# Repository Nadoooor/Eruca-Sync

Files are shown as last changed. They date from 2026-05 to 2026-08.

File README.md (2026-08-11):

# Eruca-Sync
-------
<p align="center">
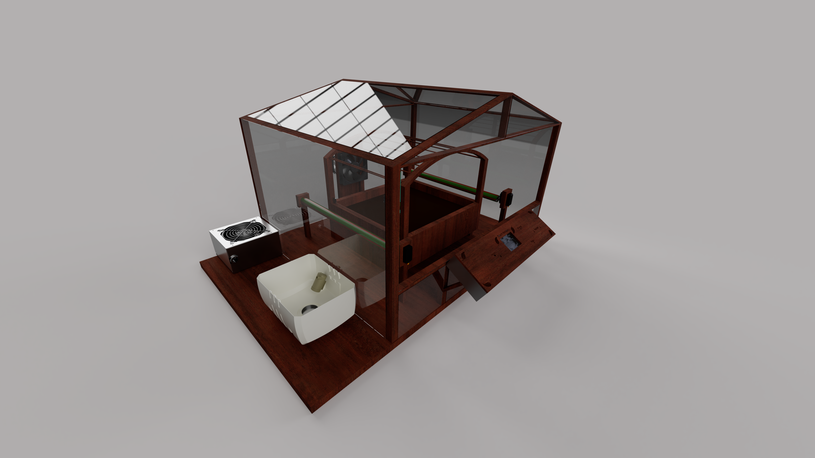
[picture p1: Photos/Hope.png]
Centered Image
  
</p>

--------
## Description:
A smart greenhouse with a closed-loop feedback system that can bring stability automatically to the system by itself. It focuses on green leafy plants and on three parameters. <br>

* Light intensity
* Soil moisture
* Temprature<br>

It has actuators that are responible of making the anti-changes that reverse any changes that occur in the environment, like temperature rise, soil drought, and over-light on the green leafy plants.<br>

### Why I am making this:
I made this because there are plants that I really want to try, but I can't plant them in my home because there is no suitable environment for them. So, the project will provide these plants with their suitable environment. For Example, around my home, I can't plant Eruca (Arugula) because of the direct sunlight and the high temperature. I really want to try planting Arugula, so I thought about how to plant it around my home, but with minimal effort. So, I got this idea to make a self-balancing environment for the Arugula or any plant species. 

### Highlight
The light mechanism is the most highlighted actuator here. It is composed of two servos and two pips, which rotate with each other to change different light transmissivity layers to increase the light intensity coming from the sun or decrease it.

## How it works:

1. First, just plug the power plug into any 220V power source. 
2. The screen will light up, asking which plant species you are planting. 
3. Choose the plant species, and that's it.
4. Leave it on its own; it will show you the real-time parameter readings as it is waiting for any changes to power up the actuators.

## Some photos of the project:

### PCB:<br>

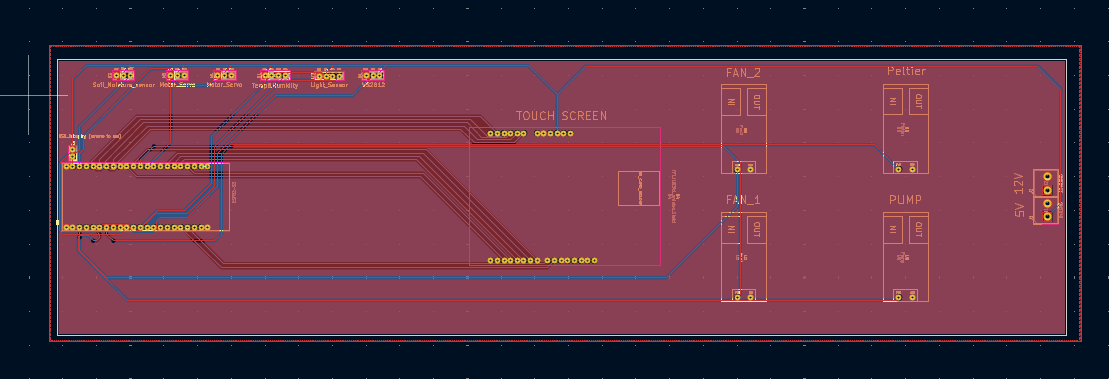
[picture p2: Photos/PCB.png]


### 3D PCB:<br>

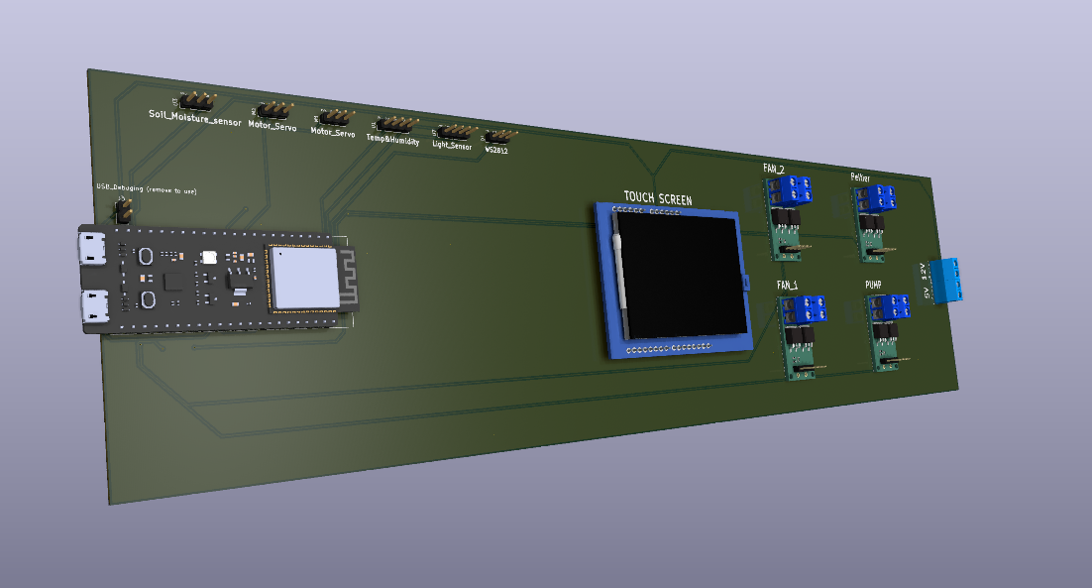
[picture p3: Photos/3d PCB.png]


### Schematic:

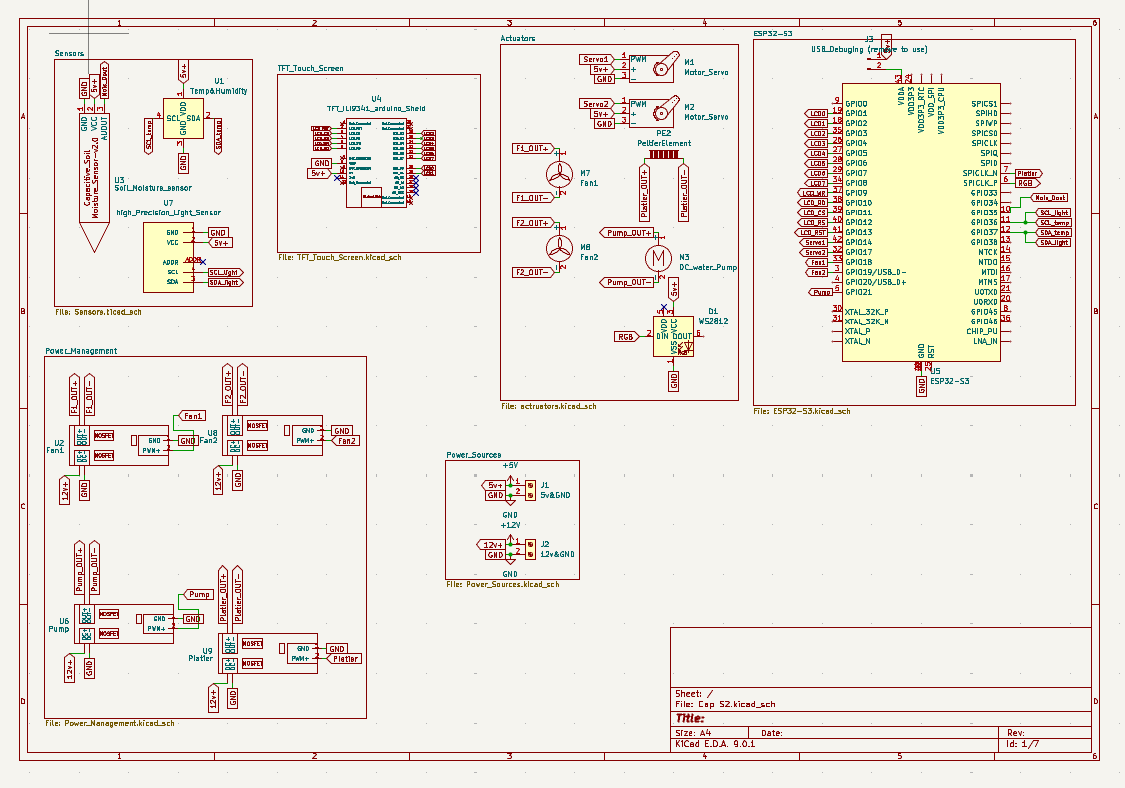
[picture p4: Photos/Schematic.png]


### 3D design:

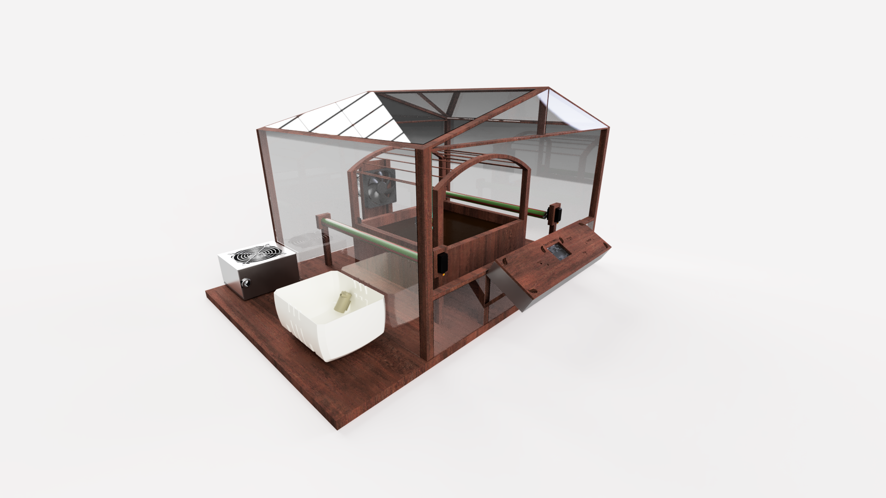
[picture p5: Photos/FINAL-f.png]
<br>
<br>
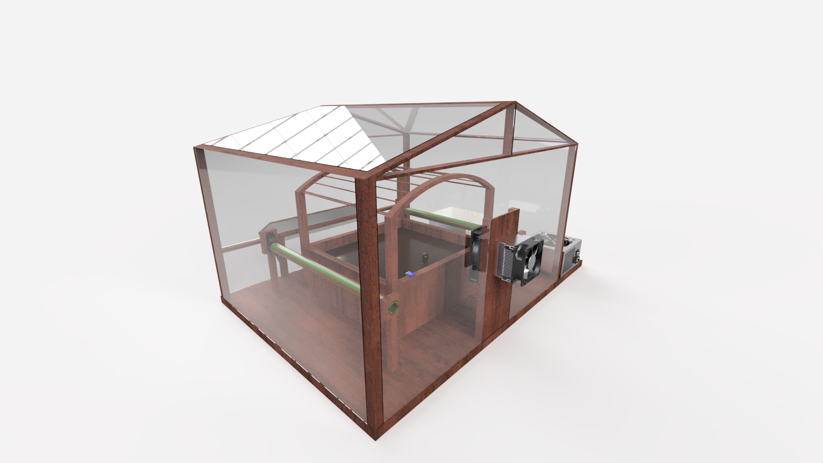
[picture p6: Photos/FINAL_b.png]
<br>

### IRL Photo:

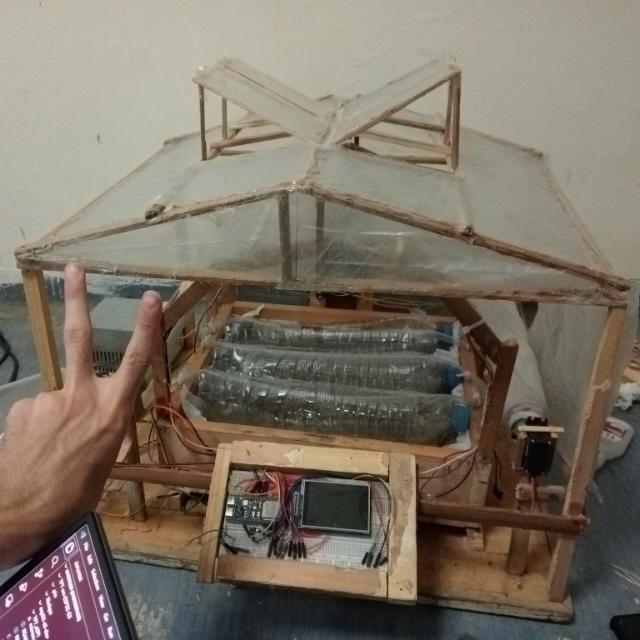
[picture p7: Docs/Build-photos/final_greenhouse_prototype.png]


> [!NOTE]
> Here you are the [Onshape Docs](https://cad.onshape.com/documents/9a096ebca3b52eda8b421bd5/w/291a79fda487721e4172dde6/e/f2d4edb63e0c7f47e937ec7d).
> Also the build journal [here](Docs/Build_Journal.md)

### Fallout Zine  :
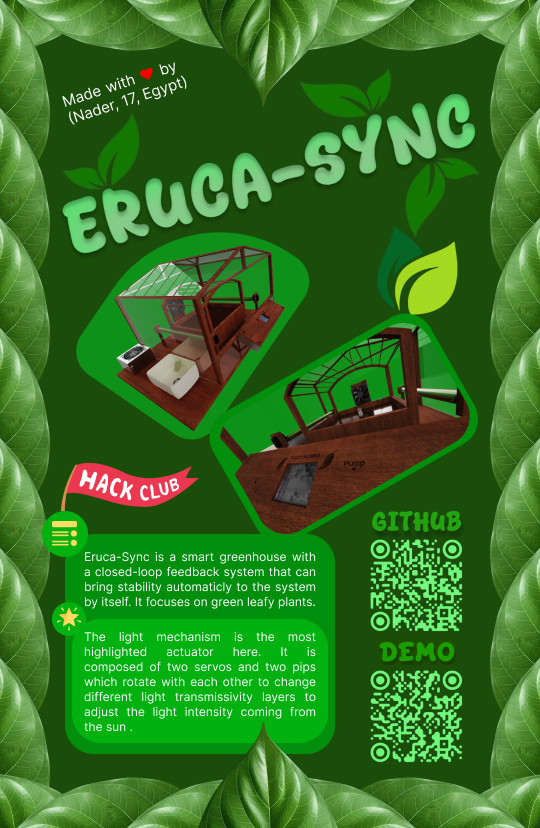
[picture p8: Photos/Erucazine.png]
<br>

## BOM (Bill of Materials)

---------------------------------------------
| Item Name | purchase links | Quantity | Price Per Unit | Total  |
|---|---|---|---|---|
| FS5106R Servo Motor 360° Continuous 6 kg.cm Plastic Gears | [Link](https://www.ram-e-shop.com/shop/servo-fs5106r-fs5106r-servo-motor-360deg-continuous-6-kg-cm-plastic-gears-7122) | 2 | $7.4 | $14.8  |
| AM-2320 Temperature & Humidity Calibrated Sensor | [Link](https://www.ram-e-shop.com/shop/sen-am2320-am-2320-temperature-humidity-calibrated-sensor-asair-r-original-brand-7776) | 1 | $3.28 | $3.28  |
| NeoPixel Stick 8-bit WS2812 5050 RGB LED | [Link](https://www.ram-e-shop.com/shop/kit-ws2812-8-5050-strip-neopixel-stick-8-bit-ws2812-5050-rgb-led-driver-development-board-8257) | 6 | $0.84 | $5.04  |
| Capacitive Analog Soil Moisture Sensor V2.0 | [Link](https://www.ram-e-shop.com/shop/sen-soil-c-capacitive-analog-soil-moisture-sensor-v2-0-sku-soil-c-8116) | 1 | $1.87 | $1.87  |
| BH1750 Light Calibrated Sensor | [Link](https://ar.aliexpress.com/item/1005009671465215.html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) | 5 | $1.31 | $6.55  |
| Water Pump 3-6Vdc Mini 120L/H | [Link](https://www.ram-e-shop.com/shop/dc-pump-6vdc-water-pump-3-6vdc-mini-120l-h-7422) | 1 | $0.84 | $0.84  |
| Thermoelectric Cooler 40x40mm - Peltier | [Link](https://www.ram-e-shop.com/shop/sf10080-thermoelectric-cooler-40x40mm-peltier-6726) | 1 | $2.81 | $2.81  |
| Aluminum Heatsink HS.13 Size 40x40x11 mm | [Link](https://www.ram-e-shop.com/shop/hs13-aluminum-heatsink-hs-13-size-40x40x11-mm-7713) | 1 | $0.52 | $0.52  |
| Kit MOSFET 15A 400W - Trigger Switch Drive Module | [Link](https://www.ram-e-shop.com/shop/kit-mosfet-15a-400w-kit-mosfet-15a-400w-trigger-switch-drive-module-with-pwm-regulator-control-8008) | 5 | $0.84 | $4.22  |
| PC Old Power Supply - 200W | [Link](https://www.dubizzle.com.eg/en/electronics-home-appliances/computers-accessories/q-power-supply/) | 1 | $2 | $2 |
| Old PC CPU Cooler with its Fan | [Link](https://www.dubizzle.com.eg/en/ad/amd-cpu-stock-fan-ID207435960.html) | 1 | $5.62 | $5.62  |
| Old PC Fan 12cm | [Link](https://www.dubizzle.com.eg/en/ad/%D9%85%D8%B1%D9%88%D8%AD%D8%A9-%D8%A7%D9%84%D9%83%D9%85%D8%A8%D9%8A%D9%88%D8%AA%D8%B1-pc-case-fan-ID207415788.html) | 1 | $1.56 | $1.56  |
| Water Container (Any bottle or box) | [Link](https://www.amazon.eg/-/en/elyassin-plastic-food-container-size/dp/B0C4K14QZV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) | 1 | $1.3 | $1.3 |
| Wood with the dimensions (all the dimensions are in the onshape) | Bro any Cabinetmaker you don't need a link for that but [At least this will help](https://goodwood.com.eg/en/new-details.php?id=5973) *(For me i used recycled wood from my school)* | ~~~ | Vary | Vary |
| LCD TFT 2.8 inch Touch Display with ILI9341 Driver 8bit Parallel | [Link](https://www.ram-e-shop.com/shop/kit-lcd-tft-2-8-touch-lcd-tft-2-8-inch-touch-display-for-arduino-uno-mega2560-8003) | 1 | $12.18 | $12.18 |
| ESP32-S3-N16R8 Development Board WIFI and Bluetooth | [Link](https://mostelectronic.com/shop/arduino-development-boards/esp32-s3-n16r8-development-board-wifi-and-bluetooth/) | 1 | $14.06 | $14.06 |
| PVC pipes as the rotation axies | As well as the wood (plz don't buy it online it is so cheap out there) | 2 x 0.5 meter | $3 | $6 |
| Plastic baggs or plastic sheets | Recycled as well | ~~~ | ~~~ | ~~~ |
| Jumper Wires | [Link](https://www.ram-e-shop.com/shop/ph61-mm-20cm-ph61-20cm-male-to-male-40-jumper-wires-set-7094) | 60 | $0.019 | $1.14  |
| Some Nails | The same place as the pipes | 30 | $0.027 | $0.8 |
| MDF Fast Adhesive Glue | [Link](https://www.amazon.eg/-/en/Akfix-705-Universal-Fast-Adhesive/dp/B07MCQWCQV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) | 2 | $3.18 | $6.36  |
| PCB | [Link](https://uge-one.com/pcb-print-design/?srsltid=AfmBOopBK8awYYikG2a9qXKbW5DigASPA7Sdrr7dOJ97qQsz4a_aT9M1) | 1 | $20 | $20|
| Shipping | ~~~~~~~~~~ | ~~~ | ~~~ | $6.74  |
| Total | ~~~~~~~~~~ | ~~~ | ~~~ | $117.69 |

## How to build the Code:
1. Install PIO (PlatformIO) and clone the repo
2. Open the Eruca-Sync-Code folder, which has the source code in PlatformIO VS Code.
3. Do whatever you want, edit, add, remove, etc.
4. Just click the check mark down there in VS Code to build the code into a .bin and .elf files.
5. Or just click the arrow icon while connecting the ESP to the PC/Laptop to directly compile and upload the code.
6. Enjoy ;)

## How to build the structure:
1. Get wood with the right dimensions(You will find them in the Onshape docs).
2. For the arc on top of the planting area, you can laser cut them along the motor and pipe holders
3. Use the Nails to install all four columns (You can, like, put the nail in its place on the base, and then take it back and cut its head and put it again, and then install the column using a hammer as I did with mine)
4. When you finish the structure using nails and wood, you can then take the fan part, and first you should cut a thin wood rectangle piece(like in the 3D), and then nail the two short columns on top of its sides.
5. Screw the PC fan and the PC cooling part 
6. After that, install the full piece with the same method as the regular columns.
7. Install the wooden planting area, which has the arc and columns on top. (with the same techniques).
8. Put the light sensor and the temperature in the middle of any side of the planting area. (you can use two lil screw or MDF glue).
9. Put the soil in the planting area (And place the soil moisture sensor in the middle of it).
10. You can connect the four outer columns with tall wooden horizontal pieces to make it stable if it is not.
11. Make two identical Rectangles for the roof with the dimensions.
12. Place them at a 30-degree angle from the horizontal so they can make a triangle with each other.
13. Install the Control Panel box on the front side of the structure at an angle of 45 degrees with two small wooden pieces under it to make it stable. (Glue the box to those pieces with MDF and use a nail on the other side in the two little columns.
14. Add the PCB and wire everything to its place on the PCB.
15. Place the power supply and the water container.
16. Use plastic bags or acrylic sheets to cover the greenhouse.
17. Upload the code 
18. That's it, enjoy. ❤️
-----------------

# Made with ❤️ By Nadooor

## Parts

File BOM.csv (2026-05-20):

Item Name | purchase links | Quantity | Price Per Unit | Total
FS5106R Servo Motor 360° Continuous 6 kg.cm Plastic Gears | https://www.ram-e-shop.com/shop/servo-fs5106r-fs5106r-servo-motor-360deg-continuous-6-kg-cm-plastic-gears-7122 | 2 | $7.4 | $14.8
AM-2320 Temperature & Humidity Calibrated Sensor | https://www.ram-e-shop.com/shop/sen-am2320-am-2320-temperature-humidity-calibrated-sensor-asair-r-original-brand-7776 | 1 | $3.28 | $3.28
NeoPixel Stick 8-bit WS2812 5050 RGB LED | https://www.ram-e-shop.com/shop/kit-ws2812-8-5050-strip-neopixel-stick-8-bit-ws2812-5050-rgb-led-driver-development-board-8257 | 6 | $0.84 | $5.04
Capacitive Analog Soil Moisture Sensor V2.0 | https://www.ram-e-shop.com/shop/sen-soil-c-capacitive-analog-soil-moisture-sensor-v2-0-sku-soil-c-8116 | 1 | $1.87 | $1.87
BH1750 Light Calibrated Sensor | https://ar.aliexpress.com/item/1005009671465215.html?curPageLogUid=4LlmP7toFGiX | 5 | $1.31 | $6.55
Water Pump 3-6Vdc Mini 120L/H | https://www.ram-e-shop.com/shop/dc-pump-6vdc-water-pump-3-6vdc-mini-120l-h-7422 | 1 | $0.84 | $0.84
Thermoelectric Cooler 40x40mm - Peltier | https://www.ram-e-shop.com/shop/sf10080-thermoelectric-cooler-40x40mm-peltier-6726 | 1 | $2.81 | $2.81
Aluminum Heatsink HS.13 Size 40x40x11 mm | https://www.ram-e-shop.com/shop/hs13-aluminum-heatsink-hs-13-size-40x40x11-mm-7713 | 1 | $0.52 | $0.52
Kit MOSFET 15A 400W - Trigger Switch Drive Module | https://www.ram-e-shop.com/shop/kit-mosfet-15a-400w-kit-mosfet-15a-400w-trigger-switch-drive-module-with-pwm-regulator-control-8008 | 5 | $0.84 | $4.22
PC Old Power Supply - 200W | https://www.dubizzle.com.eg/en/electronics-home-appliances/computers-accessories/q-power-supply/ | 1 | $2 | $2
Old PC CPU Cooler with its Fan | https://www.dubizzle.com.eg/en/ad/amd-cpu-stock-fan-ID207435960.html | 1 | $5.62 | $5.62
Old PC Fan 12cm | https://www.dubizzle.com.eg/en/ad/%D9%85%D8%B1%D9%88%D8%A2%D8%A9-%D8%A7%D9%84%D9%83%D9%85%D8%A8%D9%8A%D9%88%D8%AA%D8%B1-pc-case-fan-ID207415788.html | 1 | $1.56 | $1.56
Water Container (Any bottle or box) | https://www.amazon.eg/-/en/elyassin-plastic-food-container-size/dp/B0C4K14QZV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 | 1 | $1.3 | $1.3
Wood with the dimensions (I used recycled wood)(all the dimensions are in the onshape) | https://goodwood.com.eg/en/new-details.php?id=5973 | ~~~ | Vary | Vary
Plastic bags or plastic sheets | https://www.amazon.eg/-/en/Zpac-freezer-bag-heavy-duty/dp/B09T3HLTGR | ~~~ | ~~~ | ~~~
Jumper Wires | https://www.ram-e-shop.com/shop/ph61-mm-20cm-ph61-20cm-male-to-male-40-jumper-wires-set-7094 | 60 | $0.019 | $1.14
LCD TFT 2.8 inch Touch Display with ILI9341 Driver 8bit Parallel | https://www.ram-e-shop.com/shop/kit-lcd-tft-2-8-touch-lcd-tft-2-8-inch-touch-display-for-arduino-uno-mega2560-8003 | 1 | $12.18 | $12.18
ESP32-S3-N16R8 Development Board WIFI and Bluetooth | https://mostelectronic.com/shop/arduino-development-boards/esp32-s3-n16r8-development-board-wifi-and-bluetooth/ | 1 | $14.06 | $14.06
PVC pipes as the rotation axies | https://hegazy-group.com/products/engineering-home-pvc-elecetrical-pipe-25mm-3-meter | 2 x 0.5 meter | $3 | $6
Some Nails | https://www.amazon.eg/-/en/1-2mm-Plain-Steel-Joinery-Nails/dp/B09CDNXTX5?mcid=a3513e1143233c7d97289a4cd67e9979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 | 30 | $0.027 | $0.8
MDF Fast Adhesive Glue | https://www.amazon.eg/-/en/Akfix-705-Universal-Fast-Adhesive/dp/B07MCQWCQV | 2 | $3.18 | $6.36
PCB | https://uge-one.com/pcb-print-design/ | 1 | $20 | $20
Shipping | ~~~~~~~~~~ | ~~~ | ~~~ | $6.74
Total | ~~~~~~~~~~ | ~~~ | ~~~ | $117.69

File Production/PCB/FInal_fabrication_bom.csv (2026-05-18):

Designator | Footprint | Quantity | Value | LCSC Part #
D1 | PinHeader_1x03_P2.54mm_Vertical | 1 | WS2812
J1 | Altech_AK100_1x02_P5.00mm | 1 | 5v&GND
J2 | Altech_AK100_1x02_P5.00mm | 1 | 12v&GND
J3 | PinHeader_1x02_P2.54mm_Vertical | 1 | USB_Debuging (remove to use)
M1, M2 | PinHeader_1x03_P2.54mm_Vertical | 2 | Motor_Servo
U1 | PinHeader_1x04_P2.54mm_Vertical | 1 | Temp&Humidity
U2 | MOSFET_KIT | 1 | Fan1
U3 | PinHeader_1x03_P2.54mm_Vertical | 1 | Soil_Moisture_sensor
U4 | TFT_SCREEN | 1 | TFT_ILI9341_arduino_Sheid
U5 | ESP32-S3-DEVKITC-1 | 1 | ESP32-S3
U6 | MOSFET_KIT | 1 | Pump
U7 | PinHeader_1x04_P2.54mm_Vertical | 1 | Light_Sensor
U8 | MOSFET_KIT | 1 | Fan2
U9 | MOSFET_KIT | 1 | Platier

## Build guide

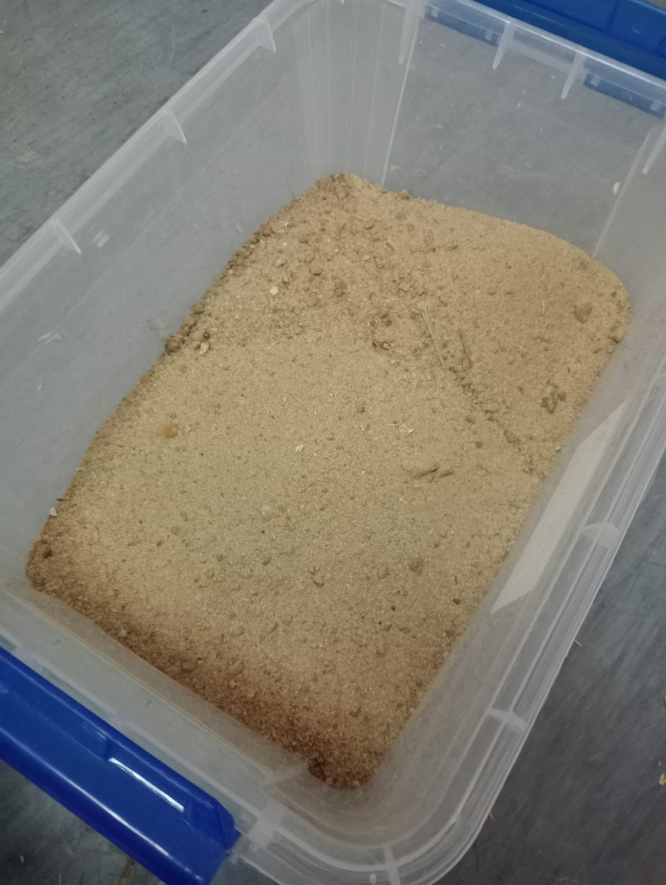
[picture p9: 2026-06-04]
Docs/Build-photos/regular sand.jpg

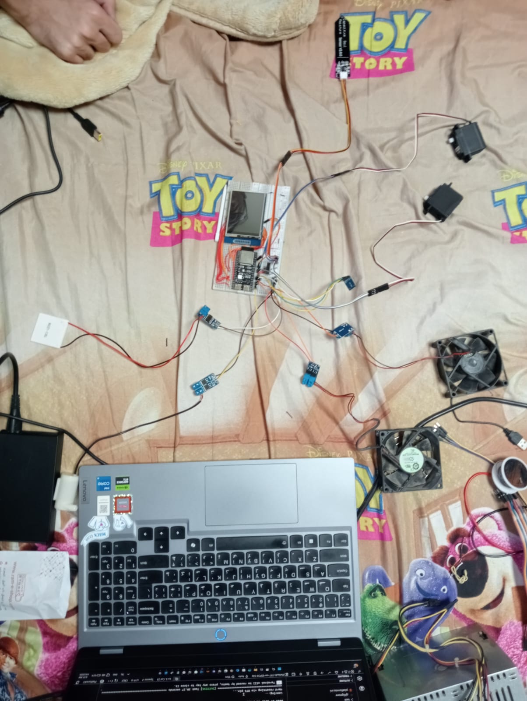
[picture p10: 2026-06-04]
Docs/Build-photos/connecting circuit for the first time.jpg

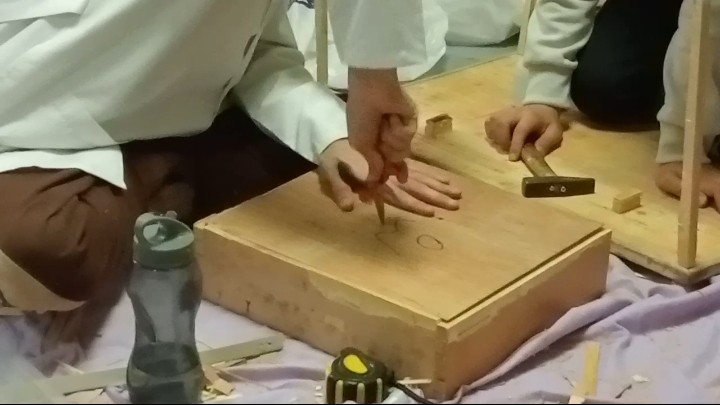
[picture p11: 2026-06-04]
Docs/Build-photos/piercing the bottom of the planting box.jpg

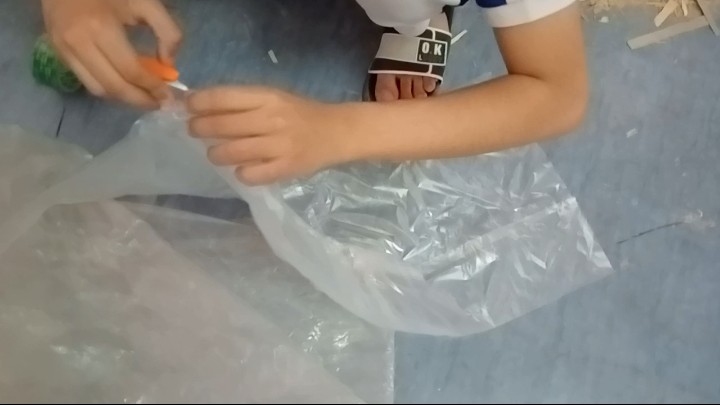
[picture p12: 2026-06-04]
Docs/Build-photos/cutting plastic sheet.jpg

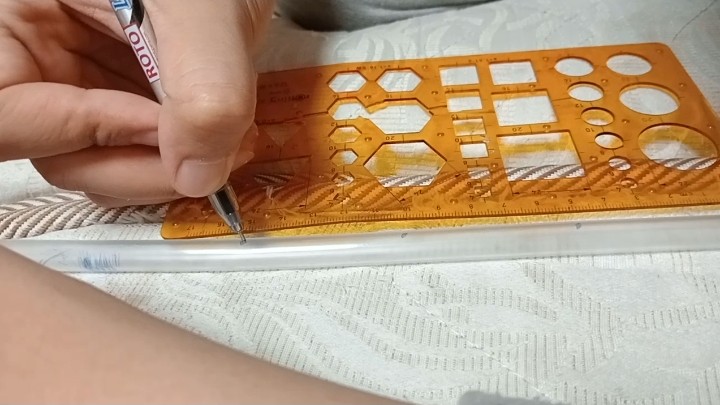
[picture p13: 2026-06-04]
Docs/Build-photos/marking the holes on the plastic tube.jpg

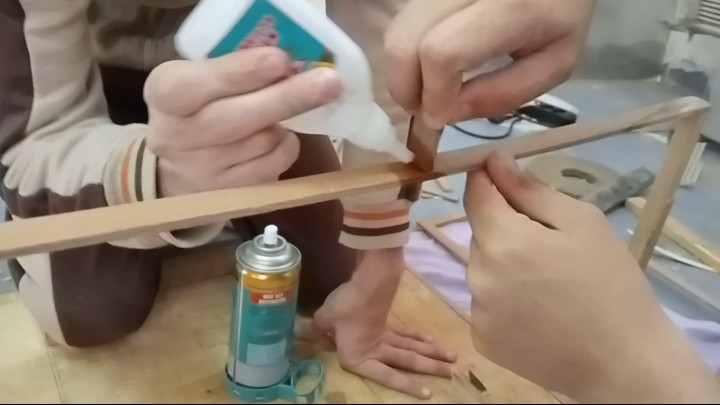
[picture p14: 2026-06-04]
Docs/Build-photos/connecting wooden pieces with MDF.jpg

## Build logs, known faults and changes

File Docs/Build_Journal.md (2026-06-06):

# Build Journal

--------------------------

### Total Build Hours: 56 Hours

<br>

## Day 1

- **Date:** 1/4/2026
- **Total hours spent:** 5 Hours

My school wants me to finish this project in just a week :C, it will be a so exhausting week, but that's fine I can do it.

Well, I was looking for a recycled wood. I kept searching until I found this super cool place on my school's backyard. 

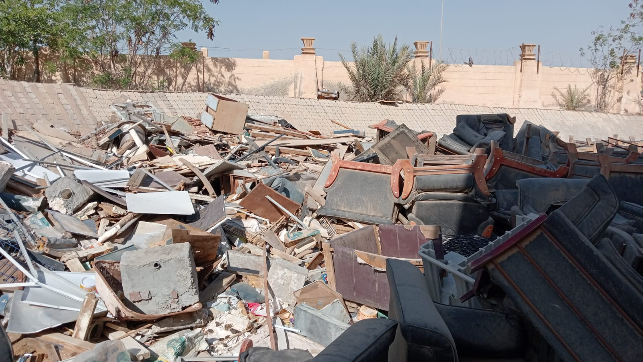
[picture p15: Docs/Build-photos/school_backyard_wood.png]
School Backyard Recycled Wood Spot


So, I took this old desk and took the top layer from it so I can use it as the base.

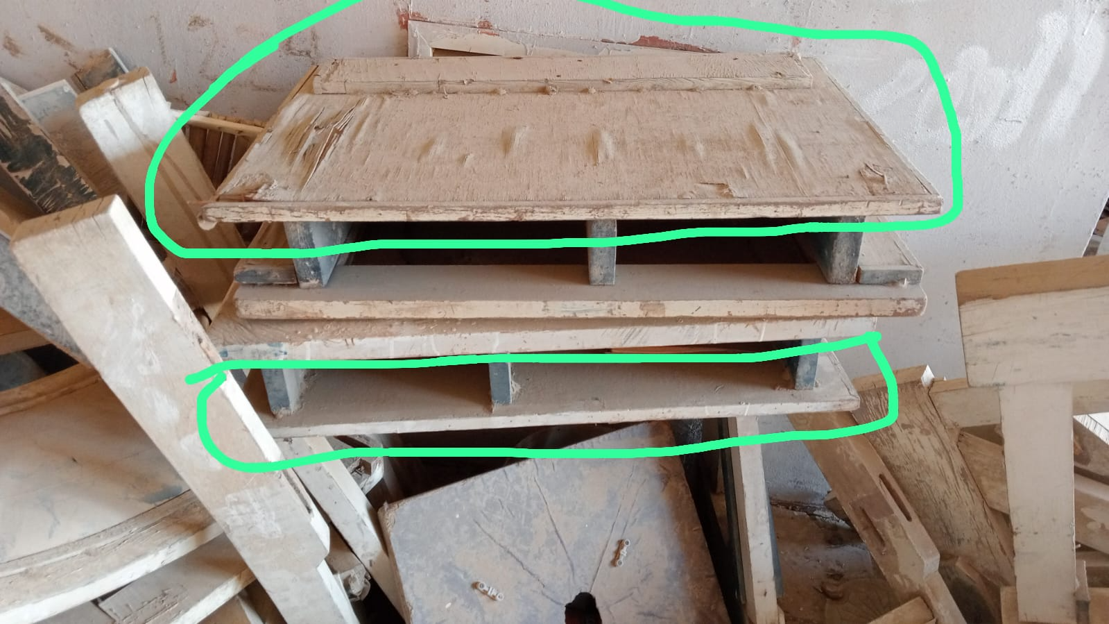
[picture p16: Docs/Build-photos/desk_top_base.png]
Old Desk Top Layer Base


I also found some materials in my home like the PVC pipe and thin wood that I can make the sealing and the supporters with it. 

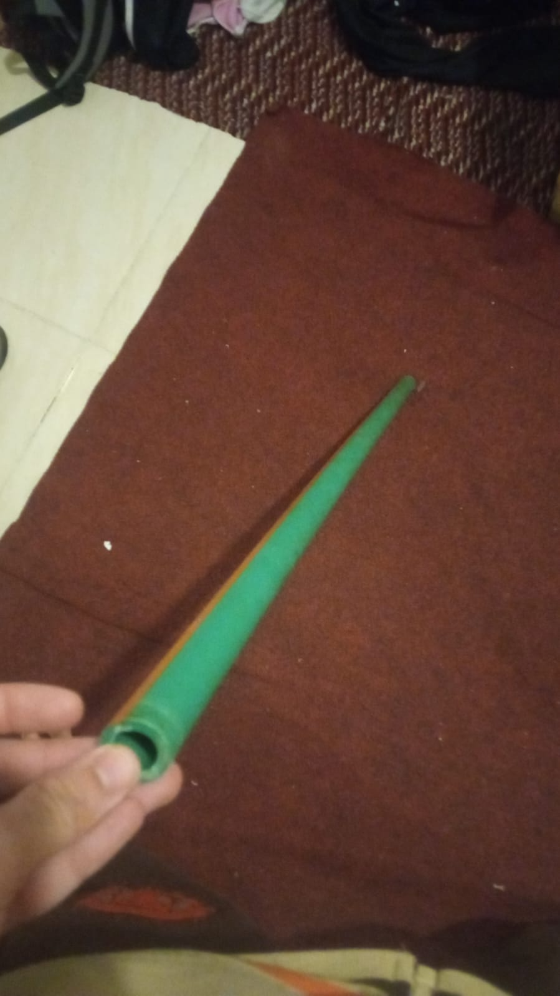
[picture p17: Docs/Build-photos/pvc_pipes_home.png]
PVC Pipes Found At Home

Thin Wood Supporters

*(The searching process didn't count on the total Hours.)*

Well, after that I started by building the outer structure. Well, I was searching for the Wood columns that I will use. But the supporter wood I found in my home can't be used as columns as it is kinda thin. 

So, I found old drawers that can be used as columns after breaking them down. 

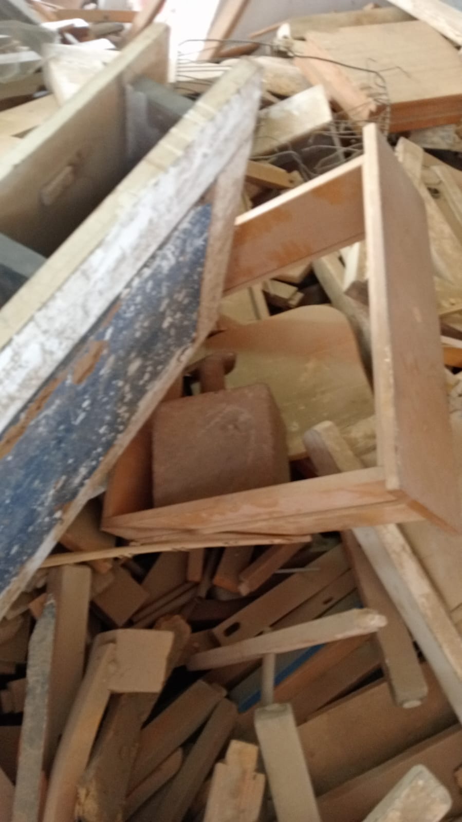
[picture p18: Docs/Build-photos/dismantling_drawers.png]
Dismantling Old Drawers For Parts

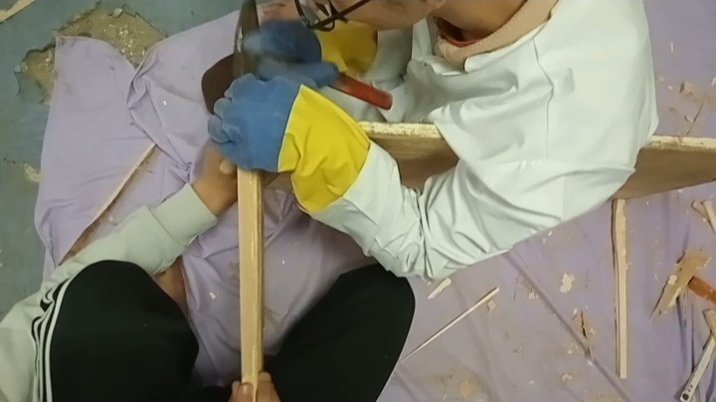
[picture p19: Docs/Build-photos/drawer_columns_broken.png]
Drawer Wood Cut Into Columns


Then I put nails from the bottom of the base to each column so they can stick to the base and also used MDF glue to make it more solid. 

After that, of course the four wooden columns won't be that super solid so I used the supporter wood pieces I made so I can connect the four columns with each other and after that they were so much solid. 

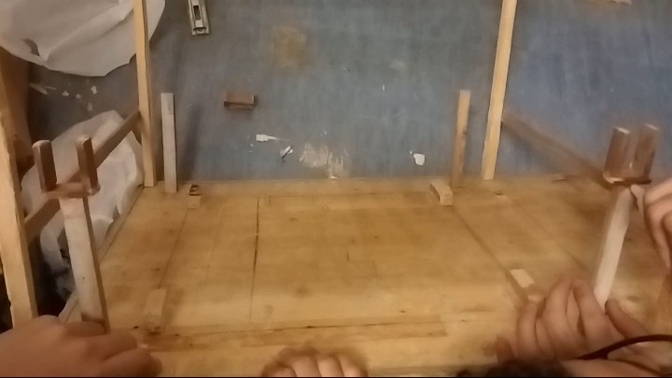
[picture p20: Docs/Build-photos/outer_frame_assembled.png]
Reinforced Outer Structure Frame


<br>

## Day 2

- **Date:** 2/4/2026
- **Total hours spent:** 7 Hours

I was very exhausted yesterday because I went to school without the bus with all the materials and ALSOOo worked on the project as I said above :c.

But now I slept well and can work a lil longer. So, let's go.

First, I started by setting up the soil for the plants and used an old full drawer for that. To prepare the planting base, I mixed the soil with peat moss and sand.

* **Video Link:** [Making the Peat Moss Soil](https://youtu.be/yI6NNnzTHSI)

And we placed an internal plastic bag so it can protect the drawer's wood from getting rotten. Once the protective layer was secure, I poured the freshly prepared mixture in.

* **Video Link:** [Pouring the Peat Moss Soil](https://youtube.com/shorts/tnRFBcnSGDY?feature=share)
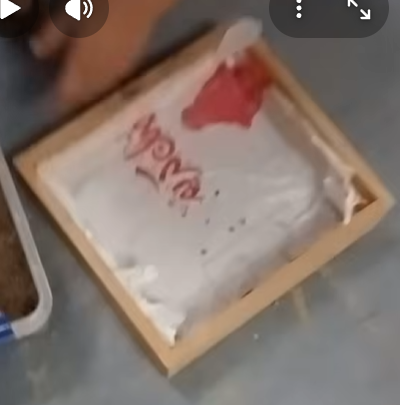
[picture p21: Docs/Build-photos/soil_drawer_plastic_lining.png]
Soil Drawer with Plastic Lining
* **Image Reference:** 

And yeah before putting the drawer into the structure, I also made another four columns for the motors and the light mechanism with its motor and PVC pipe holders. And with the same technique I used nails to reinforce them. 

After putting the soil inside the drawer, I placed the drawer inside the outer structure with some small wood pieces that will lift it a lil from the base so we can collect the water in a small plate.

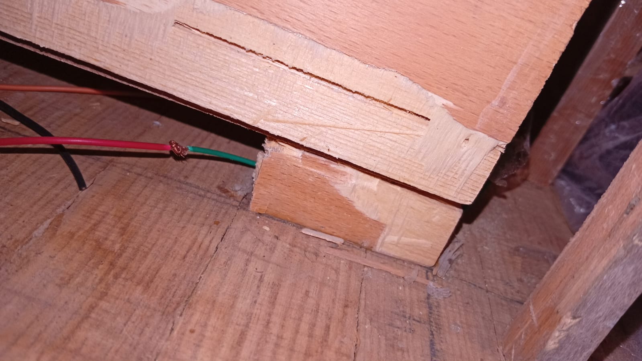
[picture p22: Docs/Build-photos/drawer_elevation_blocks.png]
Lifting Blocks Under Soil Drawer


After putting the soil drawer inside the structure, I started building the cooling system wooden structure and fans places. Well, this one needed to be built separately first and then install it into the main structure after it is considered ready. 

So, I just took a wooden thin plate and then cut it with the dimensions in the 3D, after that I got two small columns and put them on top of the wooden plate. And used nails to stick them together. 

After that I put the fans on top each side and marked the nails places, and marked also the square where the cooling Peltier will be placed. Then I cut it and placed the Peltier and added on the hot side some thermal paste and then added the PC cooling fan that came with the heat sink. On the cold side I added the heat sink with the thermal paste and then added the PC normal fan and used the screws to reinforce everything.  

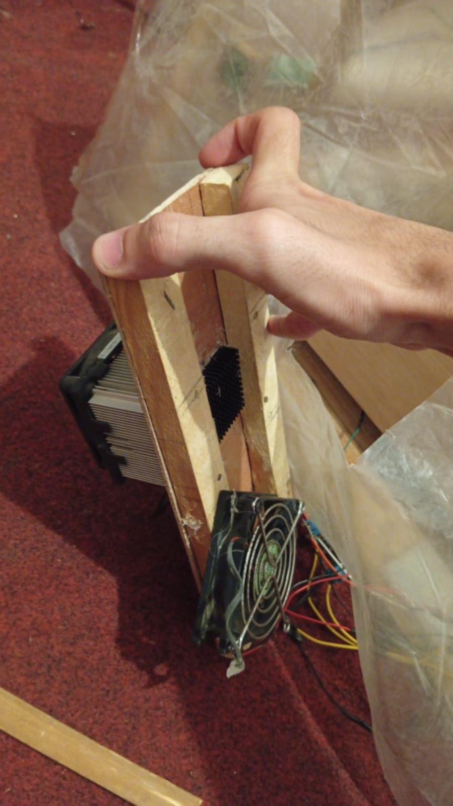
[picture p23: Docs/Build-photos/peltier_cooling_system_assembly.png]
Peltier Cooling Module Setup and Fans


After that, it's time to install this part onto the main structure. Well, as usual I used the regular technique and used nails and MDF glue to reinforce it into the main structure and yeah connected it to the supporter wood. 

After finishing that part, I worked on the sealing structure and focused on making it as like as the shape we need and I made in the 3D. 

So, I started with making two rectangles with the dimensions. But I remembered that I need to reinforce that all when I finish many other things like the arcs of the light mechanism and so on. 

So, I stopped working for today and will continue in the next session. 

<br>

## Day 3

- **Date:** 3/4/2026
- **Total hours spent:** 6.5 Hours

I can see progress yay!

After that hard time in the last session, I killed myself on the bed for exactly 4 hours and then let's WORK again. I must finish this on time. 

Well, when I remembered that I need to delay the reinforcing of the sealing, I remembered that because I thought how I will install the arc and the light mechanism.

So, here we are building this. Well, this one was so funny. At first we were trying to just cut the supporter wood as regular small rectangles and place them on top of each other with the specified angles to make it as an arc. 

We decided to make it look prettier. We cut the wooden small rectangles while they are on top of each other so we can cut them with the same angles and shape the arc as a smooth arch, not wooden pieces placed on top of each other.  

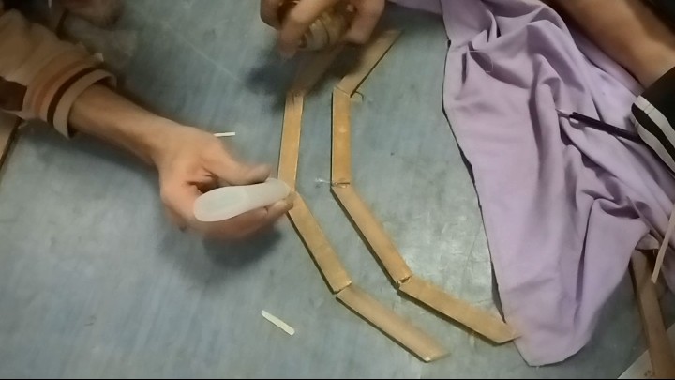
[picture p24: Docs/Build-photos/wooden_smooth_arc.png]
Shaped Wooden Smooth Arch


Well, now we need to talk about the arcs' columns which will have the arcs and the transparent bags mechanism above it. 

Ahh, this one was kinda weird. First I got the wooden columns as usual from destroying the old drawers. But when we look at the technique I was using to reinforce the columns with the nails... well, I can't do this here. This technique needs me to grab the column with my hand and put it in the required place and then using the nails and a hammer, I can drive the nail into the base from the other side through the base and to the column. But here, well the other side is too far. I can't use regular sized nails and also the tall nails can break the wood. 

So, I got a very cool idea. Well first I grabbed the columns, and using the hammer I drove the nail into the down side of the column separately without the soil drawer. I drove the nail a lil bit which can make a hole that the nail can be placed into. 

After that, I extracted the nail, and then cut its head, and then I re-drove the head side of the nail into the hole I made. After that, I grabbed the column to its place on the drawer, and finally I drove the whole column using the hammer as it works as the nail's head. 

Repeated that with the remaining 3 columns and yeah... I got these columns solid and well placed with that cool idea. I loved it so much tbh it was so funny.

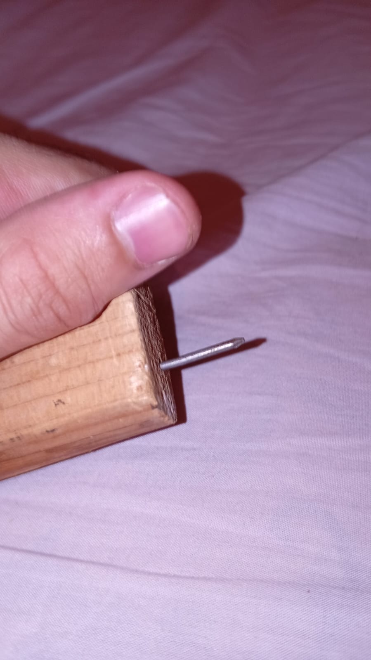
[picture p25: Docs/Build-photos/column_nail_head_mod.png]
Nail Mod Installation Hack for Columns


After this great step, I got the servo motors and connected the PVC pipes using MDF glue and very small nails into the +-shaped-gear of the servo. But at first I used the servo screw to connect the gear into the servo itself, because the screw can only be driven from the inside of the PVC pipe and it is very tall for any of my screwdrivers. 

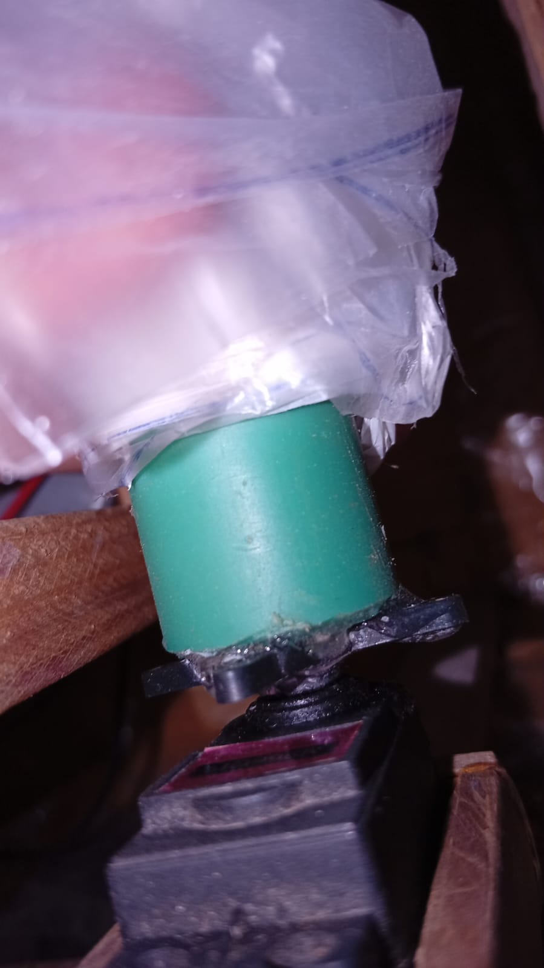
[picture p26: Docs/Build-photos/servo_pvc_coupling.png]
Servo Coupling Inside PVC Pipe


After that, I decided to make the very tall sheet of different transparent layers that will control the light intensity of the sun. Well, we took the measurement of the pipe's length and with a marker I drew the same length many times in parallel along each layer of bags so I can cut them and finally connect them with each other to make a chain of bags. Each end should be connected to the PVC pipe on each servo. 

* **Video Link:** [Testing the Light Transparent Bags Mechanism](https://www.youtube.com/shorts/U7GsUwmneE8?feature=share)

But I was very tired. So, let's call it a day and sleep the same 4-6 hours and continue work tomorrow.

<br>

## Day 4

- **Date:** 4/4/2026
- **Total hours spent:** 8 Hours

YAY, a lot of things are finished and yeah I need this time to focus on making the circuit and testing it up. 

My head hurts a lil and I didn't sleep well but I must finish this :|

Ok, started by testing up the circuit. Well, the most hard part was the screen. It was so exhausting as it has many pins and any small fault will make me search a lot about where it is. So, I made it very carefully and used small wires so it doesn't appear so overwhelming compared to the regular jumpers. 

Also, yeah I used a regular breadboard because the PCB will take time and I don't have it. It is 4 days till my exhibition and it must be fully functionable and tested. So, I used two breadboards and removed one power line from one of them and connected both of them with each other so they can perfectly size the weird ESP32-S3 width and the TFT touch screen width. 

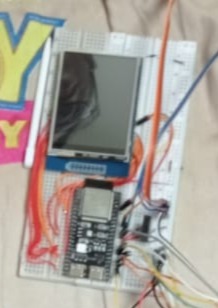
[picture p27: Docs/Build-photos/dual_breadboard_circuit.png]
Dual Breadboard Circuit Layout


After that I wired all the pins with the ESP32-S3 and found that the display doesn't want to turn on. So, I searched a lot why even the backlight doesn't want to turn on even if the backlight uses 3V3 and doesn't need 5V0. Didn't find good info on the internet tbh so I just grabbed the display myself and traced it with my eyes. And yeah I found the very stupid problem. 

Yeah the display is using a voltage regulator. And this voltage regulator must take the 5V0 and convert it into 3V3, and it can't just take 3V3 and give 3V3. So, I kept searching if I can find any jumper pads on the TFT board but I didn't find. It seems that my TFT model doesn't come with these pads. So, for now I just used an external 5V0 from the Arduino and also connected all the GNDs and just tried the TFT with the ESP32-S3 to make sure it works... and it worked! 

When I connect everything in the control panel in the prototype I can just take 5V0 from the Power Supply Unit and give it to the TFT screen and just take 3V3 from the same unit to the other components. I am using a PC power supply, so this helps so much in getting different voltages without the need of step-ups or step-downs. 

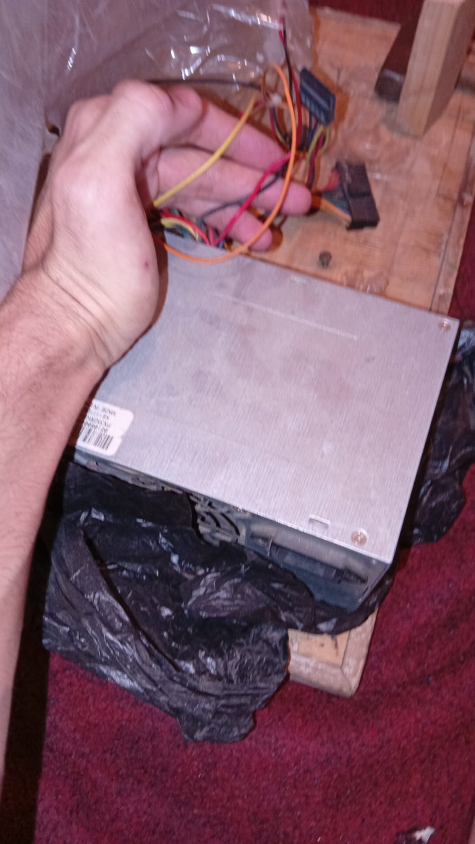
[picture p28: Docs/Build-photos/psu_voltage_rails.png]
PC Power Supply Unit Interfacing


After that I used all the remaining pins to connect the actuators and the sensors. The sensors regularly took 3.3V from the ESP32 directly. But for the actuators they were using MOSFETs so the fans and the Peltier took 12V from the PSU and the MOSFET itself gave a PWM which is connected to the ESP32 PWM pins to control the actuators. And for the water pump it is all the same except I connected it with 5V not 12V.

Tested the circuit and all the components, it was kinda weird. But after some debugging it worked. 

After that I started working on the control panel structure. Well, this one's dimensions specifically needed to be changed. Because I am using a breadboard this time which is smaller than the PCB I made. So I took the measurements of the breadboard and made a frame around it using the same drawer I destroyed and also used the same technique I used when I made the cooling system. And made two holes for the wires from the bottom side. And made another thin wooden sheet to be like the cover of the control panel, and I made a rectangle hole for the screen.

After making that wooden control panel, I made two more lil columns and placed them on the front side aligned to the other main columns. And these columns were at the same height as the supporter wood. After driving these two columns and also making two angled supporters (to make the control panel angled to the user), I placed the control panel on them (they were in the middle) and then using nails I placed its top frame stick on the columns and then I pushed the control panel a lil downwards till it touches the two angled supporters. And then using MDF to just make it stick to the two supporters and then using two very thin nails I made it very solid and well angled.

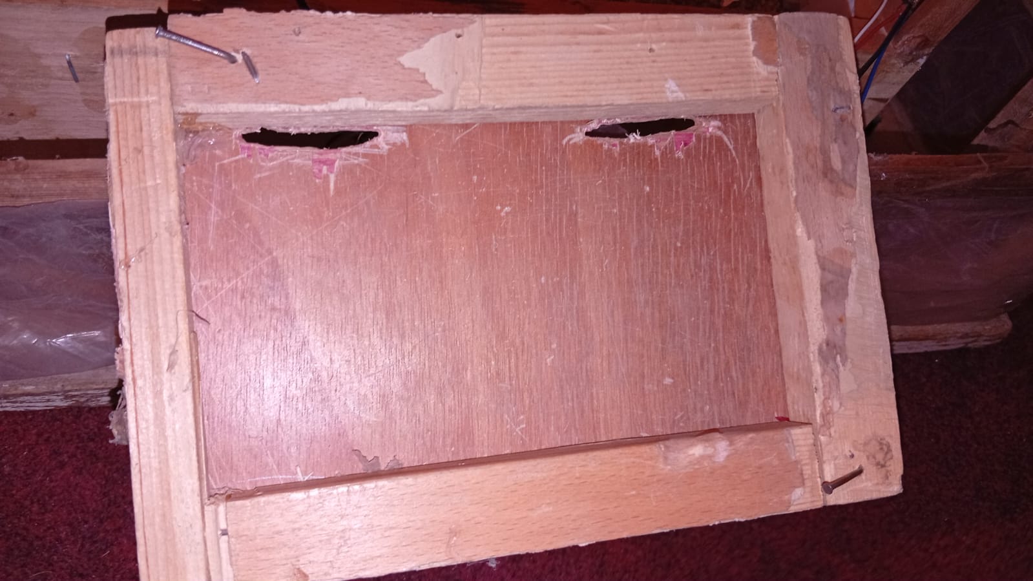
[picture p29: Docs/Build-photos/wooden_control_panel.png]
Angled Wooden Control Panel Frame


<br>

## Day 5

- **Date:** 5/4/2026
- **Hours:** 7 Hours

The project is likely at 80% progress.

Well, this time tbh I slept well so I am ready to insert all the circuit into the project.

Well, after installing the control panel on the structure, I started installing all the sensors and the actuators.

Well, I placed the breadboard that has the ESP32 and the TFT screen wired on it into the control panel structure. It fit perfectly and it was so cool and well angled. Well, the wood is not that perfect but at least I am the one who made it from scratch. 

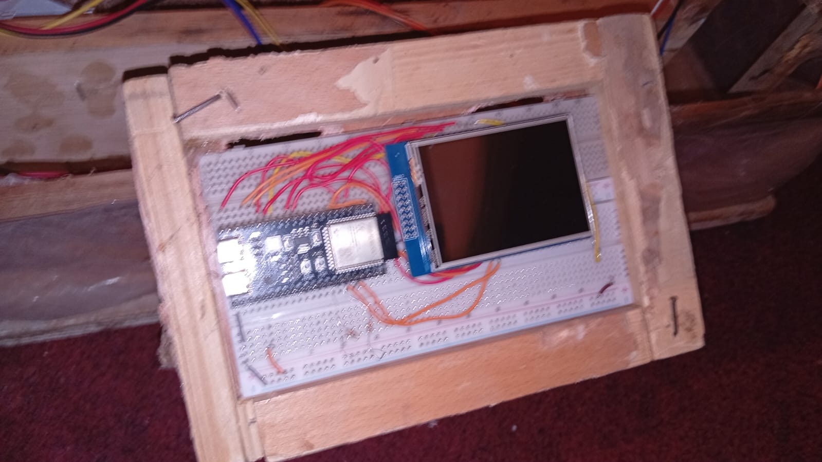
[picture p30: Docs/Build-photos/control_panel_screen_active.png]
TFT Display Running Inside Panel


After that, I placed all the sensors in their places. Placing the sensors on their places was not the problem. The wiring was the problem. It was so overwhelming because the wires had to be so long to reach the control panel. And accidentally I got short wires so I needed to connect them with each other to make one big wire and connect each sensor with 4 or 3 of these long wires. So it was kinda hard to make that all but yeah I made it. 

Well, for the actuators it was kinda different where I just needed a maximum of 2 wires for the control, and for the power also 2, but these are directly coming from the PSU. 

So I wired the fans and the Peltier and the water pump easier than the sensors. And yeah of course all of the wires are routed from the bottom of the control panel (the two holes I made). To verify the fluid integration, I mounted the automated watering system for a quick diagnostic check.

* **Video Link:** [Installing the Irrigation System for Testing](https://youtu.be/krxk9sDdObg)
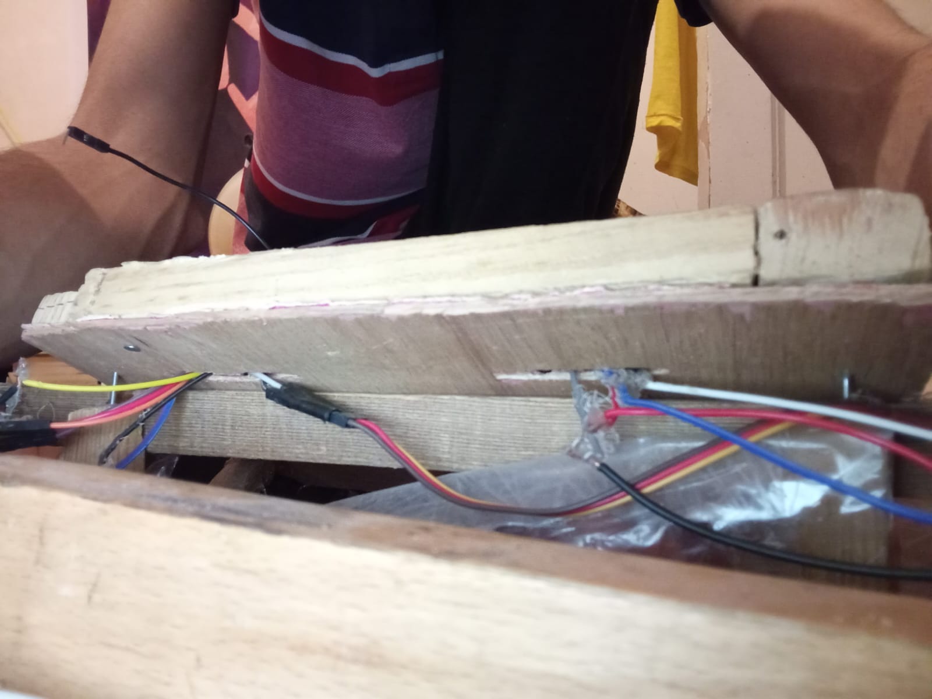
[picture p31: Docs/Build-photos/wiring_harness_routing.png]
Sensor and Actuator Wiring Paths
* **Image Reference:** 

<br>

## Day 6

- **Date:** 6/4/2026
- **Hours:** 8 Hours

Remains one thing from the circuit and the sealing and the transparent covering.

Well I must finish that all today because I need to test it twice tomorrow and after.

Ahh, the thing that took me so much time and effort to make is the NeoPixel sticks chain. This thing was a nightmare in the circuit phase. 

The NeoPixel sticks were with no connectors, no pins, no easy connection thing. You take wires and solder them on very small pads and they are very close to each other. So I must solder well without them touching each other and without a flux because I forgot to buy flux.

So I got 6 equal-in-length wires and connected each one to a pad from the three usable pads on each end of the NeoPixel stick. There were four but there are two GNDs so it only will use three on each end (GND, VCC, Din/Dout).

I made this on all the 6 neo sticks and then connected each end of a neo stick to an end of another neo stick (the Din ends with the Dout pin).

After making this huge chain I placed each neo stick in its place inside the internal drawer, and then connected the last Din in the chain to an ESP32 pin and also connected the GND and the VCC.

Should I be super happy now? Of course not, the chain soldering sometimes cracks and disconnects. So I used a glue gun on all the ends of each neo stick so it can hold connection without a lot of moving. I tried it again and yeah it worked.

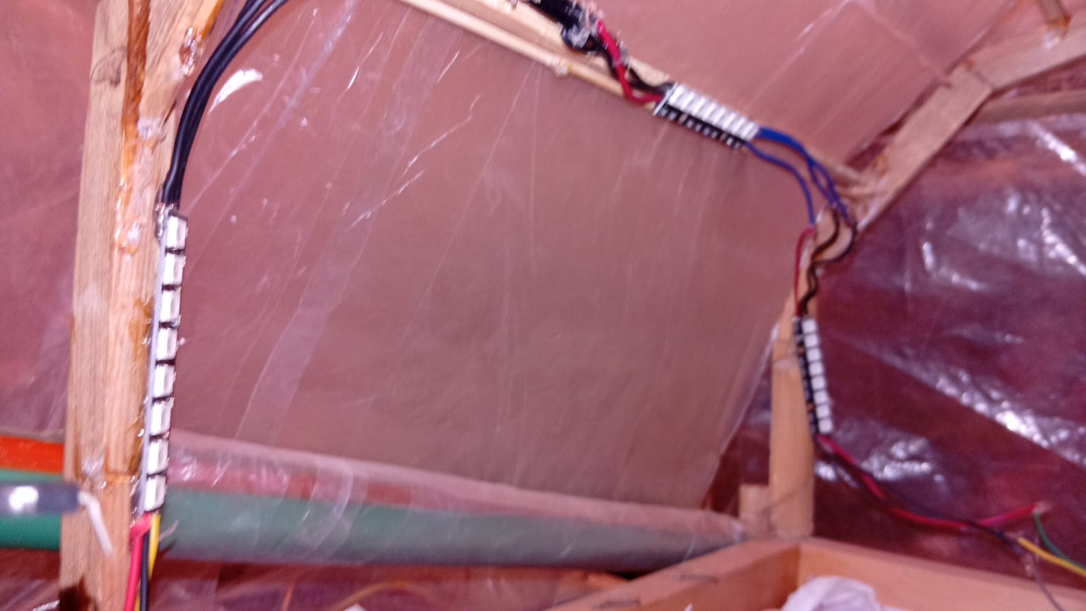
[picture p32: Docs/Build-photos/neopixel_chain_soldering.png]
Soldered NeoPixel Chain Fixed with Hot Glue


Should I be happy now? Of course noooot. I must finish it all today. So quickly I headed up to the next thing which is the sealing.

Well, we thought of making four windows on the top of the project because of thermal adaptation. So I decided to make it after I covered the project and started working on the sealing structure. I got the two rectangles I made and then put them on the top of the project and then with nails, I drove each corner into the columns so it can be solid. And of course there was another supporter wood stick under the triangles made because of the two rectangles from the front and the back. These supporters had a single very small supporter in the middle which held the triangle to be solid.

After that, I started by covering the whole project with transparent bags or sheets. I cut like rectangles for each side of the project and using a hot glue gun I placed all the rectangles in their places on all sides of the project (front, back, right, left, the two sealing rectangles and the triangles of the sealing). 

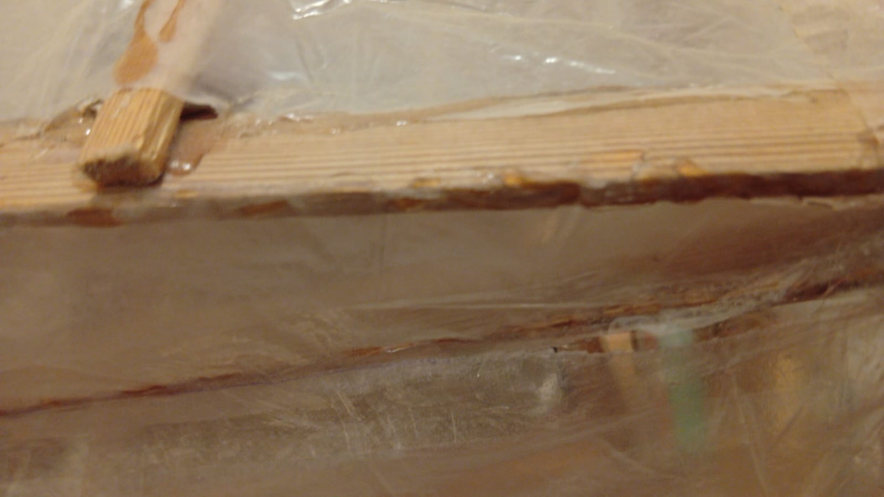
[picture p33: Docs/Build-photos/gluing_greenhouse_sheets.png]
Hot Gluing the Transparent Enclosure Sheets


After covering the project and leaving the front side not fully glued so it can work as a door, I went to check the windows we wanted to make. 

Well, these windows were easy to make. First I cut many small sticks (like 24 sticks) to make four frames and four movable windows. And after using nails and MDF to make the frames, I placed them under the cover. 

I placed the windows inside the frame and glued it to the cover and then cut three outer sides between the frames and the windows and left the back side so it can act like a hinge. And with four other small sticks I made for each window a hang stick that keeps it open. 

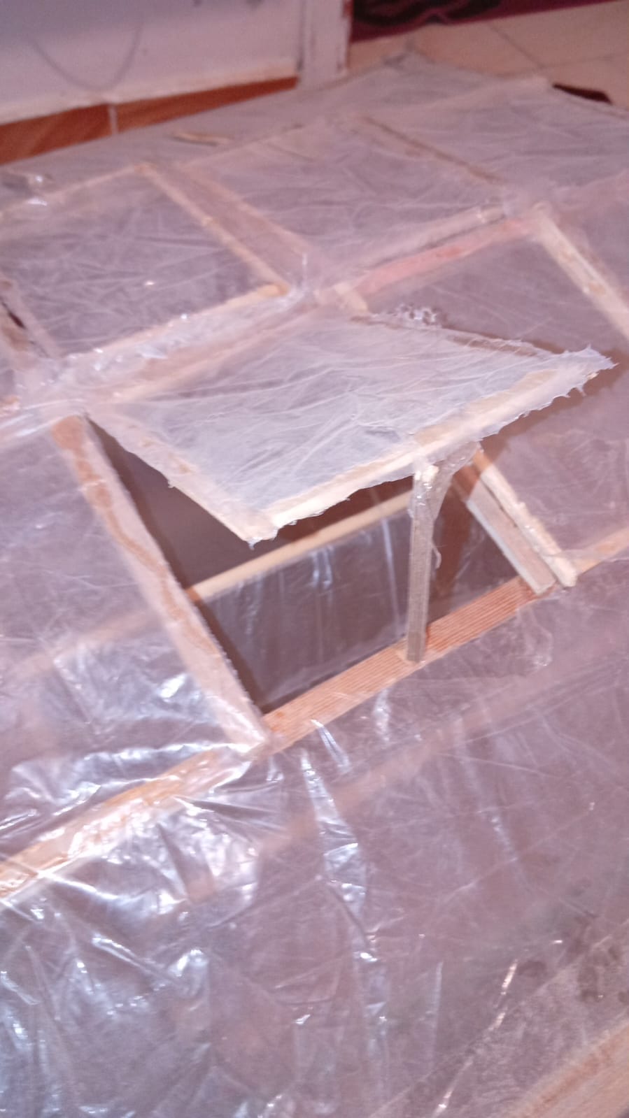
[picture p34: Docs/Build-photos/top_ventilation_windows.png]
Hand-Crafted Ventilation Hinged Windows


And yeah after all of that the project is 99% finished.

I connected all the GNDs to the PSU and also the VCC with different voltages and placed the PSU in its place and uploaded the code and made a quick check. And it all worked.

It is only remaining to make test plans tomorrow and after so we can take the best of them. We needed to capture the test plan as a time-lapsed vid so the evaluators could see it.

<br>

## Day 7

- **Date:** 7/4/2026
- **Hours:** 8 Hours

The testing day yayy.

Well, today I must fill our first 6-hour continuous test plan video. I need to confirm that the project is ready before this test.

So, I started checking the sensor readings and ran explicit calibration procedures for our diagnostic instruments to align inputs.

* **Video Link:** [Temperature Sensor Calibration (Run 1)](https://youtu.be/F82SWT_qha8)
* **Video Link:** [Temperature Sensor Calibration (Run 2)](https://youtube.com/shorts/RjeuQOubw8c?feature=share)
* **Video Link:** [Soil Moisture Sensor Calibration](https://youtube.com/shorts/Io8sj2iQW1w?feature=share)
* **Video Link:** [Light Sensor Calibration](https://youtube.com/shorts/46i1Kvqeklg?feature=share)
* **Video Link:** [Final Master Calibration Sequence](https://youtube.com/shorts/rd6x4uLS6xY?feature=share)

I noticed that the soil sensor got missed in the main file, so I recalibrated it and fixed it in the code. Then I checked the actuators. I reduced the sensor readings' ranges so the actuators can work and see them functioning.

Well, the light mechanism got stuck at the last level after checking. And I found that it was because I wrote 5 instead of 4 levels of bags, so I just edited it and it should work now.

Well, I started the 6 hours recording quickly because we didn't want to miss the hours range we are focusing to record at in the day. So, we just started and waited. 

As predicted, it is the first test so it is normal to find some failures. Well, the water pump didn't work when it should have. So, I just checked it and found that the wiring is all good, but I noticed that the GND was not connected so I just connected it and it worked. 

After this I waited again and also found another failure: the cooling fan didn't work. So, I checked the wiring and it was all good but I saw that the MOSFET wasn't getting any PWM signal. I checked the code and found that I forgot to add a HIGH value to the code after I deleted its code block and rewrote it to change the condition ranges. 

So I just paused, edited it, reflashed the code, resumed the recording, and waited to see any other problems. But I didn't find any and it worked well till the end. 

So, I need to record this again tomorrow with the same fixes and it should fully work for all the 6 hours.

<br>

## Day 8

- **Date:** 8/4/2026
- **Hours:** 6.5 Hours

I just woke up and checked the project if anyone had changed anything. But I found it all good so I just started the recording directly and waited. 

All 6 hours passed without any problems and it worked perfectly! So I will attach the time-lapsed vid and horrayyyyyyy I finished this all and I am only waiting for the evaluation day.

* **Video Link:** [The final vid we showed to the evaluator](https://youtu.be/LXKNpItwzMk)

* **Video Link:** [6-Hour Well-made Test Run (Time-Lapsed)](https://youtu.be/uwLwe9z7YVE)
* **Image Reference:** Completed Functional Prototype Front View

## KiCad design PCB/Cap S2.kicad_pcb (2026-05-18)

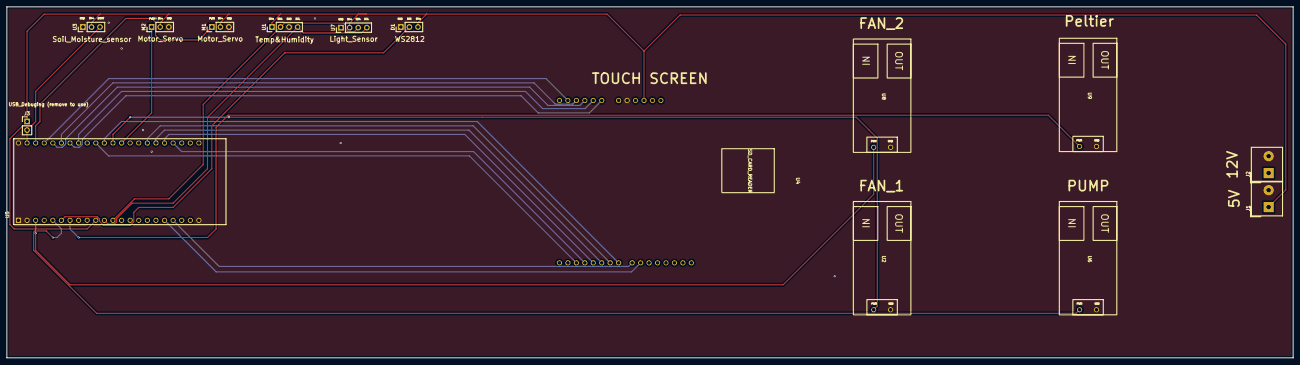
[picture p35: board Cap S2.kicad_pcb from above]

Board: 2 copper layers, 380.2 x 103.7 mm, 15 parts (0 on the bottom side), 27 nets.

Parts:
D1: WS2812; PinHeader_1x03_P2.54mm_Vertical
J1: 5v&GND; Altech_AK100_1x02_P5.00mm
J2: 12v&GND; Altech_AK100_1x02_P5.00mm
J3: USB_Debuging (remove to use); PinHeader_1x02_P2.54mm_Vertical
M1, M2: Motor_Servo; PinHeader_1x03_P2.54mm_Vertical
U1: Temp&Humidity; PinHeader_1x04_P2.54mm_Vertical
U2: Fan1; MOSFET_KIT
U3: Soil_Moisture_sensor; PinHeader_1x03_P2.54mm_Vertical
U4: TFT_ILI9341_arduino_Sheid; TFT_SCREEN
U5: ESP32-S3; ESP32-S3-DEVKITC-1
U6: Pump; MOSFET_KIT
U7: Light_Sensor; PinHeader_1x04_P2.54mm_Vertical
U8: Fan2; MOSFET_KIT
U9: Platier; MOSFET_KIT

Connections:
5v+: D1.3 (VCC), J1.1, J3.1, M1.2 (+), M2.2 (+), U1.1 (VDD), U3.2 (VCC), U4.10 (5V), U7.2 (VCC)
Fan1: U2.2 (PWM+), U5.33 (GPIO18)
Fan2: U5.3 (GPIO19/USB_D-), U8.2 (PWM+)
GND: D1.1 (VSS), J1.2, J2.2, M1.3 (-), M2.3 (-), U1.3 (GND), U2.1 (GND), U3.1 (GND), U4.8 (GND), U5.1 (GND), U5.2 (GND), U5.22 (GND), U5.44 (GND), U6.1 (GND), U7.1 (GND), U8.1 (GND), U9.1 (GND)
LCD0: U4.20 (LCD_D0), U5.19 (GPIO1)
LCD1: U4.19 (LCD_D1), U5.18 (GPIO2)
LCD2: U4.26 (LCD_D2), U5.35 (GPIO3)
LCD3: U4.25 (LCD_D3), U5.26 (GPIO4)
LCD4: U4.24 (LCD_D4), U5.27 (GPIO5)
LCD5: U4.23 (LCD_D5), U5.28 (GPIO6)
LCD6: U4.22 (LCD_D6), U5.29 (GPIO7)
LCD7: U4.21 (LCD_D7), U5.34 (GPIO8)
LCD_CS: U4.3 (LCD_CS), U5.39 (GPIO11)
LCD_RD: U4.6 (LCD_RD), U5.38 (GPIO10)
LCD_RS: U4.4 (LCD_RS), U5.40 (GPIO12)
LCD_RST: U4.2 (LCD_RST), U5.41 (GPIO13)
LCD_WR: U4.5 (LCD_WR), U5.37 (GPIO9)
Mois_Dout: U3.3 (AUOUT), U5.10 (GPIO35)
unnamed: J3.2, U5.43 (VDDA)
unnamed: U5.23 (VDD3P3), U5.24 (VDD3P3)
Platier: U5.7 (SPICLK_N), U9.2 (PWM+)
Pump: U5.5 (GPIO21), U6.2 (PWM+)
RGB: D1.2 (DIN), U5.6 (SPICLK_P)
SCL_light: U1.4 (SCL), U5.11 (GPIO36), U7.4 (SCL)
SDA_light: U1.2 (SDA), U5.12 (GPIO37), U7.3 (SDA)
Servo1: M1.1 (PWM), U5.42 (GPIO14)
Servo2: M2.1 (PWM), U5.32 (GPIO17)

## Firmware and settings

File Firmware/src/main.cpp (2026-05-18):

#include <Arduino.h>
#include <Wire.h>
#include <TFT_eSPI.h>       
#include <TouchScreen.h>
#include <BH1750.h>
#include <ESP32Servo.h>
#include <Adafruit_NeoPixel.h>
#include <Adafruit_AM2320.h>
  

#define YP 12 
#define XM 11 
#define YM 1  
#define XP 2  

#define I2C_SDA 37
#define I2C_SCL 36

#define Peliter_pin 48
#define NEOs_pin 47
#define FAN1_pin 16
#define FAN2_pin 17
#define PUMP_pin 21
#define Soil_pin 35
#define ServoL_pin 14
#define ServoR_pin 17

TouchScreen ts = TouchScreen(XP, YP, XM, YM, 300);
TFT_eSPI tft = TFT_eSPI();
BH1750 lightMeter;
Adafruit_AM2320 am;
Servo ServoL;
Servo ServoR;
Adafruit_NeoPixel pixels(48, NEOs_pin, NEO_GRB + NEO_KHZ800);
float currentTemp = 0;
float currentMoist = 0;
float currentLux = 0;

bool tempStatus = false;
bool moistStatus = false;
bool lightStatus = false;

enum SYSMOD{MENU, ARGULA, SPINACH};

SYSMOD sysmod = MENU;

//Parameters  and limits for the feedback system

int mode = 0; //0 for spinach, 1 for argula

float targetTemp = 0;
float min_temp = 0; 
float max_temp = 0;
float targetMoist = 0;
float targetlux = 0; 
float min_lux = 0;
float max_lux = 0;
int irrigation_time = 0;

float Argula_targetTemp = 20.0;
float Argula_min_temp = 18.0; 
float Argula_max_temp = 22.0;
float Argula_targetMoist = 60.0;
float Argula_targetlux = 10800; 
float Argula_min_lux = 9990;
float Argula_max_lux = 11610;
int Argula_irrigation_time = 11800;
int currentlevel = 0; 

//temp
float Spinach_targetTemp = 25.0;
float Spinach_min_temp = 23.0; 
float Spinach_max_temp = 27.0;

//moisture
float Spinach_targetMoist = 70.0;
//light
float Spinach_targetlux = 8100; 
float Spinach_min_lux = 7290;
float Spinach_max_lux = 8910;
float Spinach_irrigation_time = 18610;



float calibed_soil(float raw){
    float calibed = map(raw,3241,1491,0,100);
    if (calibed < 0){
      calibed = 0;
    }
    else if (calibed > 100){
      calibed = 100;
    }
    
      return calibed;
    
}

float calibed_lux(float raw){
    return 0.9985 * raw;
}

float calibed_temp(float raw){
    return 1.054 *raw - 0.2272;
}


float measurePtemp(class Adafruit_AM2320 am){
    return calibed_temp(am.readTemperature());
}

float measurelight(class BH1750 lightMeter){
    return calibed_lux(lightMeter.readLightLevel());
}
float measuremoist(){
    return calibed_soil(analogRead(Soil_pin));
}


void statics(){
    tft.fillScreen(TFT_BLACK);
    tft.fillRect(0, 0, 320, 35, TFT_NAVY);
    tft.setTextColor(TFT_WHITE);
    tft.drawCentreString("Eruca Sync", 160, 8, 2);
    tft.drawFastHLine(0, 85, 300, TFT_SILVER);
    tft.drawFastHLine(0, 140, 300, TFT_SILVER);

    tft.drawFastVLine(160, 45, 145, TFT_SILVER);
    tft.setTextColor(TFT_WHITE);
    tft.drawString("TEMP:",15, 45, 2);
    tft.drawString("MOIST:", 170, 45, 2);
    tft.drawString("LUX:", 15, 95, 2);
    tft.drawString("ACTUATORS:", 170, 95, 2);
}


void menu(){
    tft.fillScreen(TFT_BLACK);
    tft.setTextColor(TFT_WHITE);
    tft.drawCentreString("Select Plant", 160, 40, 4);


    tft.fillRect(20, 100, 130, 80, TFT_DARKGREEN);
    tft.fillRect(20,100,130,80, TFT_WHITE);
    tft.drawCentreString("Argula", 85, 130, 2);

    tft.fillRect(170, 100, 130, 80, TFT_MAROON);
    tft.fillRect(170,100,130,80, TFT_WHITE);  
    tft.drawCentreString("Spinach", 235, 130, 2);  

}


void refreash(){
    tft.setTextColor(TFT_CYAN, TFT_BLACK);
    tft.drawString(String(currentTemp, 1) + " C", 15, 60, 4);
    tft.setTextColor(TFT_BLUE, TFT_BLACK);
    tft.drawString(String(currentMoist, 1) + " %", 170, 60, 4);
    tft.setTextColor(TFT_YELLOW, TFT_BLACK);
    tft.drawString(String(currentLux, 0) + " lx", 15, 110, 4);

    tft.setTextSize(1);
    tft.setTextColor(tempStatus ? TFT_GREEN : TFT_RED, TFT_BLACK);
    tft.drawString(tempStatus ? "Cooling: ON" : "Cooling: OFF", 170, 115, 2);
    tft.setTextColor(moistStatus ? TFT_GREEN : TFT_RED, TFT_BLACK);
    tft.drawString(moistStatus ? "Irrigation: ON" : "Irrigation: OFF", 170, 135, 2);
    tft.setTextColor(lightStatus ? TFT_GREEN : TFT_RED, TFT_BLACK); 
    tft.drawString(lightStatus ? "Shading: ON" : "Shading: OFF", 170, 155, 2);

}



void logic(){
    //temp_logic
    if (mode == 1){
    targetlux = Argula_targetlux;
    targetMoist = Argula_targetMoist;
    targetTemp = Argula_targetTemp;

    max_lux = Argula_max_lux;
    min_lux = Argula_min_lux;

    max_temp = Argula_max_temp;
    min_temp = Argula_min_temp;
    irrigation_time = Argula_irrigation_time;
    }
    else if (mode == 0){
    targetlux = Spinach_targetlux;
    targetMoist = Spinach_targetMoist;
    targetTemp = Spinach_targetTemp;

    max_lux = Spinach_max_lux;
    min_lux = Spinach_min_lux;

    max_temp = Spinach_max_temp;
    min_temp = Spinach_min_temp;

    irrigation_time = Spinach_irrigation_time;
    
}

if(currentTemp > max_temp){
    analogWrite(FAN1_pin, 255);
    analogWrite(FAN2_pin, 255);
    analogWrite(Peliter_pin, 255);
    tempStatus = true;
    
}
else if (currentTemp < min_temp){
    analogWrite(FAN1_pin, 0);
    analogWrite(FAN2_pin, 0);
    analogWrite(Peliter_pin, 0);
    tempStatus = false;
} else {
    Serial.println("There is a problem with the temperature sensor");
}


if (currentMoist < 50 && currentMoist > 10){
    moistStatus = true;
    analogWrite(PUMP_pin, 255);
    delay(irrigation_time);
    analogWrite(PUMP_pin, 0);
    moistStatus = false;
} else if (currentMoist <= 10){
    analogWrite(PUMP_pin, 0);
    moistStatus = false;
} else if (currentMoist >= 85){
    analogWrite(PUMP_pin, 0);
    moistStatus = false;
}

if (currentLux < min_lux && currentLux >= 0){
    if(currentlevel > 0){
        lightStatus = true;
        ServoL.write(45); ServoR.write(135);
        currentlevel--;
        delay(9500);
        ServoL.write(90); ServoR.write(90);
        lightStatus = false;
    
    } else if (currentlevel == 0){
        for (int i = 0; i < 48; i++){
            pixels.setPixelColor(i, pixels.Color(128, 0, 32));
            pixels.show();
            delay(50);
        }
    }

} else if (currentLux > max_lux && currentlevel< 4){
    for (int i = 0; i < 48; i++){
            pixels.setPixelColor(i, pixels.Color(0, 0, 0));
            pixels.show();
            delay(50);
        }
        lightStatus = true;
    ServoL.write(135); ServoR.write(45);
    currentlevel++;
    delay(9500);
    ServoL.write(90); ServoR.write(90);
    lightStatus = false;
} else {
    ServoL.write(90); ServoR.write(90);
    lightStatus = false;
}



}

void setup() {
    Serial.begin(115200);
    tft.init();
    tft.setRotation(3);

    pinMode(Peliter_pin, OUTPUT);
    pinMode(FAN1_pin, OUTPUT);
    pinMode(FAN2_pin, OUTPUT);
    pinMode(PUMP_pin, OUTPUT);
    pinMode(Soil_pin, INPUT);
    pinMode(NEOs_pin, OUTPUT);
    ServoL.attach(ServoL_pin);
    ServoR.attach(ServoR_pin);
    pixels.begin();
    pixels.setBrightness(100);

    Wire.begin(I2C_SDA, I2C_SCL, 100000);
    am.begin();
    lightMeter.begin(BH1750::CONTINUOUS_HIGH_RES_MODE, 0x23, &Wire);
    menu();
}

void loop() {
    if (sysmod == MENU){
        TSPoint p = ts.getPoint();

        pinMode(XP, OUTPUT);
        pinMode(YP, OUTPUT);

        if (p.z > ts.pressureThreshhold){

            int16_t x_calibed = map(p.x, 390, 3683, 0, 320);
            int16_t y_calibed = map(p.y, 3408, 471, 0, 240);

            if (x_calibed > 20 && x_calibed < 150 && y_calibed > 100 && y_calibed < 180){
                mode = 1;
                sysmod = ARGULA;
                tft.fillScreen(TFT_BLACK);
                statics();
            } else if (x_calibed > 170 && x_calibed < 300 && y_calibed > 100 && y_calibed < 180){
                mode = 0;
                sysmod = SPINACH;
                tft.fillScreen(TFT_BLACK);
                statics();
            }

        }





    }else {
    float Stemp = 0;
    float Slux = 0;
    float Smoist = 0;

    for (int i = 0; i < 3; i++){
        Stemp += measurePtemp(am);
        Slux += measurelight(lightMeter);
        Smoist += measuremoist();
        delay(1000);
    }
    currentTemp = Stemp/3;
    currentLux = Slux/3;
    currentMoist = Smoist/3;
    refreash();


    logic();
    }
}

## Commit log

2026-05-18 Added the BOM
    [BOM.csv]
2026-05-18 Added the PCB and putted the production files in one folder
    [Cap S2.kicad_pcb, Cap S2.kicad_sch, ESP32-S3.kicad_sch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]
2026-05-18 BOM edit
    [BOM.csv]
2026-05-18 Oops,, forgot the schematic photo
2026-05-20 Update total cost and add the forgotten PCB in BOM.md
    Updated total cost to reflect the addition of PCB.
2026-05-20 Add PCB to BOM and update total cost
    [BOM.csv]
2026-05-20 Update BOM.csv to change 'Store' to 'Links'
    [BOM.csv]
2026-05-20 fix organization to be good with fallout review
    [BOM.csv, Cap S2.kicad_pcb, Cap S2.kicad_sch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]
2026-05-20 Change 'Links' header to 'purchase links' in BOM.csv
    Updated the column header from 'Links' to 'purchase links' in BOM.csv.
    [BOM.csv]
2026-05-20 Update purchase links in BOM documentation
2026-05-20 Revise BOM.csv with new links and item details
    Updated links and descriptions for several items in the BOM.
    [BOM.csv]
2026-05-20 hope it works now
    [BOM.csv]
2026-05-20 Add BOM section to README with item details
    Added a Bill of Materials section with item details, purchase links, quantities, and prices.
2026-05-20 Revise BOM.csv with new items and formatting fixes
    Updated BOM.csv to include new items and correct formatting.
    [BOM.csv]
2026-05-20 Modify PCB entry in BOM.csv
    Updated PCB entry to include quantity and corrected format.
    [BOM.csv]
2026-05-20 Update URL for Aluminum Heatsink product
    [BOM.csv]
